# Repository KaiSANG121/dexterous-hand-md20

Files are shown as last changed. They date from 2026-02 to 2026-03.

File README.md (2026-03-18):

# Dexterous Hand Control System for Precision Grasping

A robotics project focused on **precision grasping**, **embedded control**, and **hardware-software integration** using an Arduino-based dexterous hand prototype.

This project presents a dexterous hand control system designed to improve grasp stability for objects of different sizes through a staged control strategy. The system combines a **pinch-first grasping mechanism**, **position-synchronized follower fingers**, and a **fine adjustment mode** for small-object manipulation.

The thumb and index finger are driven by **LV-TTL motors** to perform the primary pinch action, while the remaining three fingers are driven by **PWM servos** to provide follow-up wrapping support. To improve reliability and reduce latency during prototyping, a **button-based control interface** was adopted instead of Bluetooth communication.

---

## Project Highlights

- **Pinch-first grasping strategy** for initial object capture
- **Load-threshold stop logic** for safer and more stable contact
- **Position-synchronized follower fingers** for coordinated wrapping
- **Fine adjustment mode** for small-object grasping
- **Low-latency button-based control** for reliable prototyping
- **Integrated embedded control and robotic hardware implementation**

---

## Motivation

Dexterous robotic grasping requires both precise initial contact and stable follow-up wrapping. In low-cost prototypes, simple open-loop control often leads to unstable grasps, delayed response, or poor performance on small targets.

Dexterous hand precision grasping demo

This project explores a lightweight and practical control solution that balances:

1. **stable initial pinch contact**,
2. **coordinated finger wrapping**,
3. **limited fine adjustment for small or difficult objects**.

The goal was not only to make the hand move, but to design a control strategy that is **interpretable**, **tunable**, and **effective in real hardware tests**.

---

## System Overview

The system is built around an **Arduino controller** and consists of two main actuation groups:

- **Pinch fingers:** thumb and index finger driven by LV-TTL motors for initial object capture
- **Follower fingers:** three PWM-driven fingers for synchronized wrapping after pinch contact

The system uses a **button-based interface** to trigger grasping, opening, and fine adjustment actions. This design was chosen to reduce control latency and improve repeatability during hardware testing.

### Hardware Components

- Arduino Mega2560 (or Mega2560 Pro)
- 2 × LV-TTL motors (pinch fingers)
- 3 × PWM servos (follower fingers)
- push buttons for interaction
- power supply and wiring interface

---

## From Concept to Prototype

<table>
  <tr>
    <td align="center"><b>Concept Design</b></td>
    <td align="center"><b>Physical Prototype</b></td>
  </tr>
  <tr>
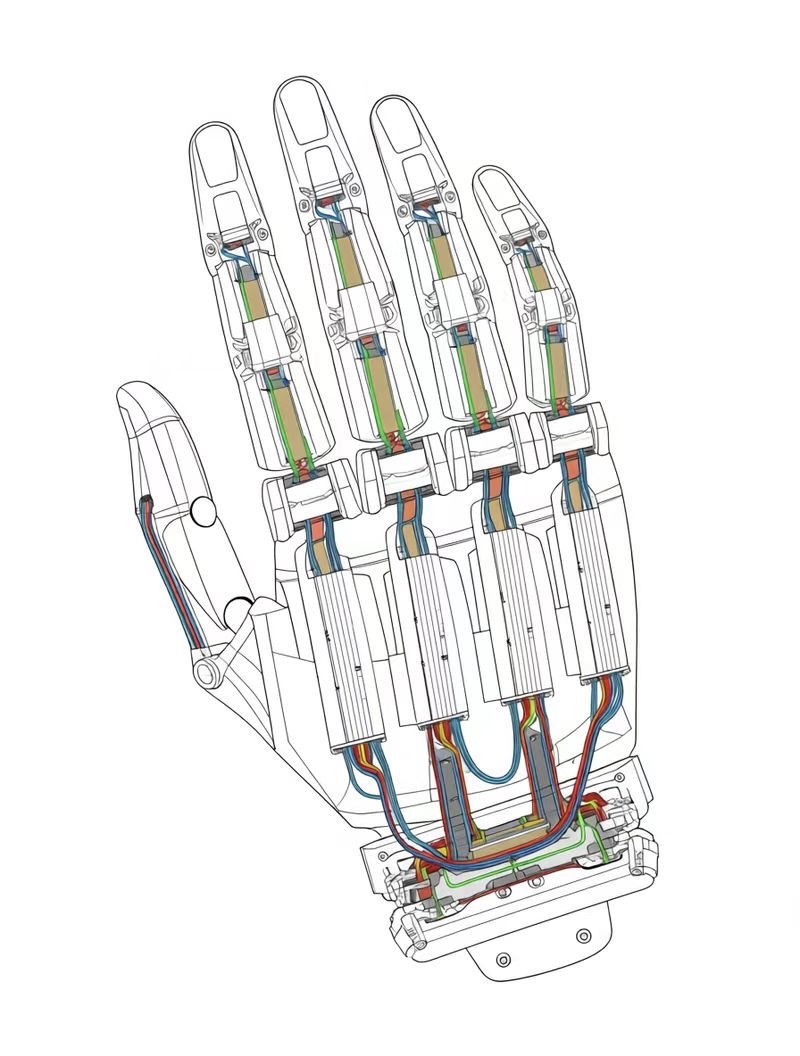
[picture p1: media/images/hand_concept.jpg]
    <td></td>
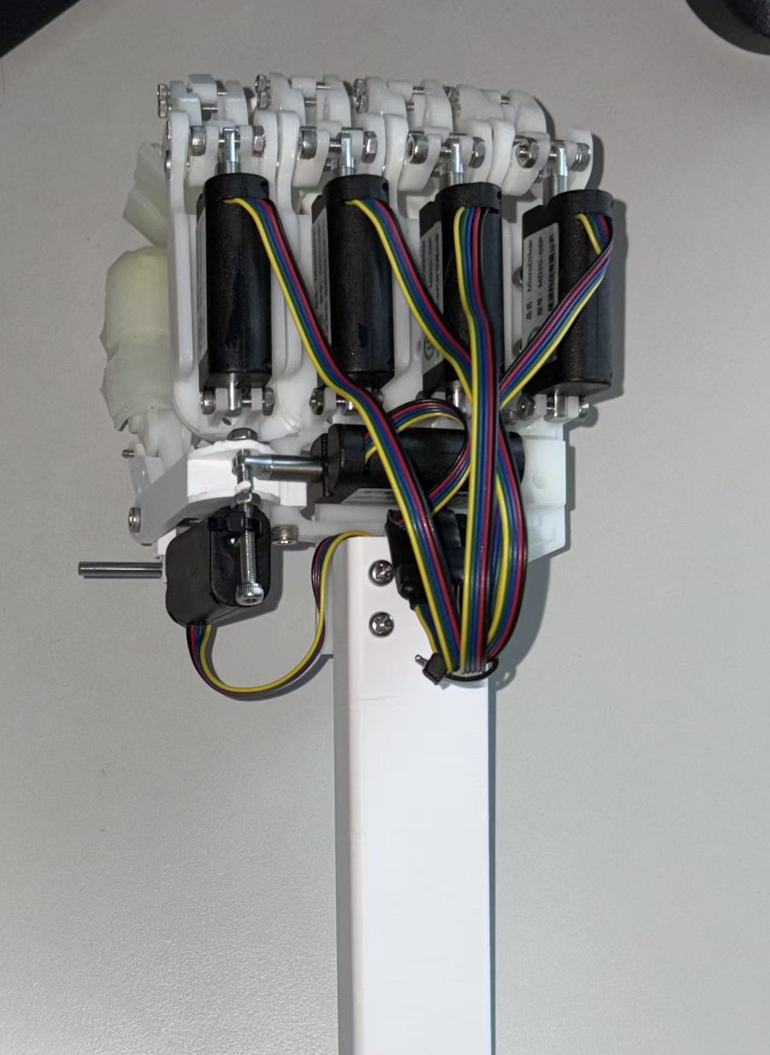
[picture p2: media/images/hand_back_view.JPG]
    <td></td>
  </tr>
</table>

This comparison shows the transition from the early structural concept to the implemented hardware prototype.  
The final system preserves the overall back-side actuator layout and finger arrangement while adapting the design for practical assembly, wiring, and embedded control integration.

---

## Control Strategy

The control logic consists of four main stages.

### 1. Open State
The hand remains open and ready for a new grasp.

### 2. Pinch Phase
The thumb and index finger move toward each other until contact is detected through a **load-threshold condition**.

### 3. Wrap Phase
After pinch contact, the remaining three fingers move according to a **position-synchronized mapping strategy**, improving overall grasp stability.

### 4. Fine Adjustment Phase
For small or difficult objects, an additional **fine adjustment step** is used to slightly refine finger position and improve grasp success.

This staged strategy separates **initial capture** from **grasp stabilization**, making the system easier to tune and analyze during testing.

---

## Design Trade-off: Buttons vs Bluetooth

Although Bluetooth control offers greater flexibility, it introduced additional latency and reduced repeatability during early-stage hardware testing. Since this project focused on **grasp reliability** and **rapid prototyping**, a button-based interface was chosen as a more stable and lower-latency solution.

This reflects an important engineering trade-off:

- sacrificing some communication convenience,
- in order to improve robustness and repeatability during prototype validation.

---

## Wiring and Pin Map

| Module | Connection |
|---|---|
| LV-TTL Motor 1 | Thumb / pinch finger |
| LV-TTL Motor 2 | Index / pinch finger |
| PWM Servo 1 | Follower finger 1 |
| PWM Servo 2 | Follower finger 2 |
| PWM Servo 3 | Follower finger 3 |
| Button A (GRIP) | Grasp trigger |
| Button B (OPEN) | Open / release |
| Button C & D | Fine adjustment for thumb |
| Button E & F | Fine adjustment for index |
| Button G (STOP) | Emergency stop |
| Button H (SYNC) | Synchronized follower fingers |

This table is the hardware role mapping. For exact firmware pin/interface mapping (and to keep README consistent with firmware), see [`docs/wiring.md`](docs/wiring.md).

---

## Key Parameters

The system behavior is mainly affected by the following parameters:

- **motion limits** for pinch fingers
- **load threshold** for contact detection
- **position mapping** between pinch motor and follower fingers
- **fine adjustment step size**
- **initial open position calibration**

A complete calibration and tuning guide is maintained in [`docs/calibration.md`](docs/calibration.md).

---

## Experimental Results

The prototype was tested on objects of different sizes and manipulation tasks. A concise quantitative summary is shown below.

### Quantitative Summary

| Task | Trials | Success | Success Rate |
|---|---:|---:|---:|
| Ping-pong ball grasp | 30 | 30 | 100.0% |
| Rubik's cube grasp | 30 | 30 | 100.0% |
| Water bottle (half full) grasp | 30 | 26 | 86.7% |
| Thumbtack grasp (fine adjust) | 30 | 11 | 36.7% |
| Card pick & insertion | 50 | 46 | 92.0% |
| Bottle cap loosening | 50 | 19 | 38.0% |

### Main Observations

- medium and large objects could be grasped with high stability,
- small objects were more sensitive to alignment and finger position,
- the fine adjustment mode improved grasp feasibility for small targets,
- synchronized follower fingers improved wrapping support after the initial pinch.

For full logs and notes, see [`results/grasp_tests.csv`](results/grasp_tests.csv) and [`results/grasp_summary.md`](results/grasp_summary.md).

---

## Limitations and Future Work

While the current prototype demonstrates stable grasping for medium and large objects, several limitations remain:

- small, thin, or low-friction objects are still difficult to grasp reliably,
- the current system relies on threshold-based contact handling rather than richer tactile sensing,
- follower fingers improve grasp wrapping but do not yet adapt independently to object geometry,
- the overall control strategy is still relatively simple and does not include full closed-loop grasp optimization.

Possible future improvements include:

- grasp success rate comparison across object categories,
- ablation study (pinch only vs pinch + sync vs pinch + sync + fine adjust),
- response time measurement for contact stop and adjustment,
- failure case analysis for small, thin, and low-friction objects,
- adding tactile or force sensing,
- improving closed-loop coordination across all fingers,
- introducing object-specific grasp planning.

---

## Repository Structure

```text
dexterous-hand-md20/
├── docs/           # design notes, calibration, wiring
├── firmware/       # Arduino control code
├── hardware/       # wiring, BOM, hardware-related files
├── media/          # demo videos and images
├── results/        # grasp logs, summaries, test outputs
└── README.md
```

## How to Run

1. Install **Arduino IDE** (recommended 2.x series, e.g. 2.3+).
2. Install required dependency library:
   - `Servo.h` (Arduino Servo library).
3. Open firmware:
   - `firmware/arduino/code/dexterous_hand_controller.ino`.
4. Configure board and serial settings:
   - Board: **Arduino Mega or Mega 2560**,
   - Port: the COM/TTY port connected to your controller,
   - Serial Monitor baud rate: **115200**.
5. Connect motors, servos, and buttons according to [`docs/wiring.md`](docs/wiring.md).
6. Upload firmware, power the system, verify initial open position, and test GRIP/OPEN/SYNC/FINE functions.
7. Tune parameters following [`docs/calibration.md`](docs/calibration.md) if needed.

---

## Media

- Demo GIF: [`media/gifs/demo.gif`](media/gifs/demo.gif)
- Video list and top demonstrations: [`media/videos.md`](media/videos.md)

---

## About the Author

This project reflects my interest in robotic manipulation, embedded control, and hardware-software integration. I focused on control architecture, embedded implementation, hardware-software integration, and iterative grasp testing.

Kaiyang Deng  
Robotics Engineering, South China University of Technology  
GitHub: KaiSANG121

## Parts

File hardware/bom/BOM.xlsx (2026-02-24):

Part Name | Parameter | Cost(¥) | Perchase Link
3D Printed Part | ABS， 0.5mm, Solid | 306.22 | 【淘宝】https://e.tb.cn/h.7Z7FRmGumVoTlou?tk=uKgxfrW5uFN MF287 「3D打印服务模型定制金属abs加工零件手板塑料模具尼龙树脂三D打样」 点击链接直接打开 或者 淘宝搜索直接打开
Nail pick | stainless steel | 13.8 | 【淘宝】7天无理由退货 https://e.tb.cn/h.7ZGgextyRJyaMKB?tk=ogYFfrdvzEo HU926 「不锈钢食指套拇指拨片 银色金色吉他指套民谣指套拨片电吉他指套」 点击链接直接打开 或者 淘宝搜索直接打开
Screws, nuts | stainless steel, M2, M2.5, M3, Hex socket | 81.44 | 【淘宝】假一赔四 https://e.tb.cn/h.70CN3nhS3ggPNhz?tk=rnvZfrWg9KT HU926 「304不锈钢内六角螺丝螺母套装大全螺钉配套组合螺栓M2M3M4M5M6M8」 点击链接直接打开 或者 淘宝搜索直接打开
Gloves | rubber | 7.21
Arduino mega2560 | ATmega2560, 5V, 54 I/O, 16 analog inputs, 16MHz, USB Mini, 38x55mm |  | 【淘宝】https://e.tb.cn/h.7ZGgLPIR855fboq?tk=B7pxfrdEO5d HU591 「STM32F103C8T6最小系统板 STM32单片机开发板套件同款科协江科大」 点击链接直接打开 或者 淘宝搜索直接打开
Sensors |  | 66.95
Vertical tact switch | 6*6*5mm | 2.41
LM2596 multi-channel switch | 3.3V/5V/12V/ADJ, DC

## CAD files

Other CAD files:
hardware/cad/dwg/设计图.DWG
hardware/cad/step/后右.STEP
hardware/cad/step/新底座.STEP
hardware/cad/step/零件10.STEP
hardware/cad/step/F03_Thumb_joint(1).STEP
hardware/cad/step/后左.STEP
hardware/cad/step/前左.STEP
hardware/cad/step/前右.STEP
hardware/cad/step/DIP (1)_3.STEP
hardware/cad/step/零件11.STEP
hardware/cad/step/F03_Thumb_base(1).STEP

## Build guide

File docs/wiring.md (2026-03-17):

# Wiring Guide

This document records the hardware wiring used by the current firmware (`firmware/arduino/code/dexterous_hand_controller.ino`).

## Pin / Interface Mapping

| Module | Connection | Pin / Interface |
|---|---|---|
| LV-TTL Motor 1 | Thumb / pinch finger | `Serial1` (TX1=18, RX1=19) |
| LV-TTL Motor 2 | Index / pinch finger | `Serial2` (TX2=16, RX2=17) |
| PWM Servo 1 | Follower finger 1 | D2 |
| PWM Servo 2 | Follower finger 2 | D6 |
| PWM Servo 3 | Follower finger 3 | D10 |
| Button A (GRIP) | Grasp trigger | D42 |
| Button B (OPEN) | Open / release | D40 |
| Button C | Fine adjustment for thumb (IN) | D25 |
| Button D | Fine adjustment for thumb (OUT) | D27 |
| Button E | Fine adjustment for index (IN) | D29 |
| Button F | Fine adjustment for index (OUT) | D31 |
| Button G (STOP) | Emergency stop | D20 |
| Button H (SYNC) | Synchronized follower fingers | D22 |

## Wiring Notes

- Button inputs use `INPUT_PULLUP` in firmware: released = `HIGH`, pressed = `LOW`.
- Ensure **common ground (GND)** between Arduino, LV-TTL motor power, and servo power.
- Verify power supply current is sufficient for simultaneous servo movement.
- Test with low-speed and emergency STOP available before full-speed operation.

## Firmware Source of Truth

If this document and firmware diverge, firmware definitions are authoritative:

- Button pins: `kBtnOpen`, `kBtnGrip`, `kBtnStop`, `kBtnSync`, `kBtnFineInM1`, `kBtnFineOutM1`, `kBtnFineInM2`, `kBtnFineOutM2`
- PWM pins: `kPwmPins = {2, 6, 10}`
- LV-TTL serial interfaces: comments and motor configuration near the top of the file

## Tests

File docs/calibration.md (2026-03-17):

# Calibration Guide (MD20 LV-TTL + PWM follower fingers)

This document explains how the key parameters in `firmware/arduino/code/dexterous_hand_controller.ino` were calibrated.

## 1. Safety checklist (before calibration)
- Use **low speed** first: `kSpeedOpen/kSpeedClose = 5~10`
- Keep fingers away from hard stops; avoid long time stall
- Ensure **common GND** between Arduino and motor power supply
- Prepare **STOP button (D20)** for emergency hold

---

## 2. LV-TTL motion limits: `kPosMin` / `kPosMax`
**Purpose:** define safe open/close endpoints (avoid hard mechanical stops)

### Procedure
1. With no object in hand, press **OPEN** and observe the thumb+index pair.
2. Slowly move toward open direction and find the **mechanically safe open pose**.
3. Record the corresponding MD20 position as `kPosMin` (current: `80`).
4. Slowly move toward close direction (empty) and find the **safe close pose** (no hard stall).
5. Record the MD20 position as `kPosMax` (current: `320`).

### Tuning tips
- If fingers hit hard stops → **reduce** the limit range (increase `kPosMin` or decrease `kPosMax`)
- If open is not wide enough → **decrease** `kPosMin` carefully (only if still safe)

---

## 3. Load-threshold pinch: `kLoadThreshold`
**Purpose:** stop each LV-TTL finger when contact is detected (load/torque proxy from MD20)

### Observed load range (example)
- **Ping-pong ball grasp:** load ≈ **35 ~ 55**
- We set `kLoadThreshold = 40` so that:
  - empty-close load stays mostly below threshold
  - object contact reliably crosses threshold

### Procedure (recommended)
1. Empty close (no object): press **GRIP**, observe `Load=` prints in Serial Monitor.
2. Grasp typical objects (e.g., ping-pong ball): press **GRIP**, observe contact load.
3. Choose threshold:
   - slightly above empty-close baseline
   - below typical contact load
4. Verify: both sides should stop and hold without continuous stalling.

### Tuning tips
- If it stops too early (weak pinch) → **increase** `kLoadThreshold`
- If it crushes objects / stalls too hard → **decrease** `kLoadThreshold`
- If load readings fluctuate a lot → increase `kMonitorIntervalMs` or reduce speed

---

## 4. PWM follower mapping: `kPwmPulseAtPosMin/Max`
**Purpose:** after pinch, let follower fingers wrap around the object for more friction and stability.

### Finger mapping (this project)
- PWM #1 (D2)  → **Middle finger**
- PWM #2 (D6)  → **Ring finger**
- PWM #3 (D10) → **Pinky**

### Endpoint calibration logic
The firmware does a linear mapping from **Motor2 (index)** position ratio to PWM pulse width:

- At `kPosMin` (open): `kPwmPulseAtPosMin = {1080, 680, 680}`
- At `kPosMax` (close): `kPwmPulseAtPosMax = {1300, 1060, 1120}`

### Procedure
1. Put the index finger (Motor2) at `kPosMin`.  
2. For each PWM finger, adjust pulse until it reaches the desired “open” pose. Record as `kPwmPulseAtPosMin[i]`.
3. Put Motor2 at `kPosMax`.
4. For each PWM finger, adjust pulse until it reaches the desired “wrap/close” pose. Record as `kPwmPulseAtPosMax[i]`.
5. Test **SYNC**: follower fingers should track smoothly as Motor2 moves.

### Tuning tips
- If a PWM finger moves opposite direction → swap min/max pulses for that finger
- If a finger saturates too early → widen pulse range slightly (within safe bounds)
- If servo jitters → ensure stable power supply and common ground

---

## 5. Fine adjustment: `kFineStep` / `kFineFastRegionEnd`
**Purpose:** improve precision for small objects (e.g., thumbtack) without sacrificing speed.

Current values:
- `kFineStep = 40`
- `kFineFastRegionEnd = 280`

### Tuning tips
- For small objects, reduce step size (e.g., `20`) for higher precision
- If fine adjust is too slow, increase step size (e.g., `50~60`)
- Keep the region split to avoid many tiny moves near the endpoint

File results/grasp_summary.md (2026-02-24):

# Grasp & Manipulation Benchmark Summary

This project is evaluated on two levels:
1) **Grasping** (pick & hold objects)
2) **Manipulation** (perform tasks beyond grasping, requiring alignment / insertion / torsion)

---

## 1. Overall Results

### Grasping (object pick & hold)
- **Medium / large rigid objects** (ping-pong ball, Rubik’s cube, half-full water bottle): typically **high success**  
  Key factor: **pinch + full-hand wrap** provides stable normal force and friction.
- **Compliant / deformable objects** (nylon rope, bagged milk, glasses cloth): typically **high success**  
  Key factor: **wrap** reduces slip and stabilizes contact on deformable surfaces.
- **Small objects** (thumbtack): ~**30%** success  
  Primary bottleneck: **pose accuracy** and **contact geometry sensitivity**.

### Manipulation (task completion)
- **Card pick & insertion**: requires **alignment + fine adjustment**  
- **Loosening bottle cap**: requires **torsion + anti-slip stability**, wrap helps maintain grip

> Detailed logs are in `results/grasp_tests.csv`.

---

## 2. Why the design works (mechanism-level explanation)

### (A) Load-threshold pinch (thumb + index, LV-TTL)
During GRIP, each LV-TTL motor closes until `load > kLoadThreshold`, then stops at current pose.
- Prevents excessive squeeze and reduces stall risk
- Provides a consistent “contact detected” event for higher-level behaviors

### (B) Full-hand wrap via SYNC (3× PWM follower fingers)
After pinch contact, pressing SYNC maps **index Motor2 position ratio** to PWM pulses and wraps the object.
- Increases total contact area
- Increases friction and stability
- Especially helpful for deformable objects (rope, fabric, bagged items) and heavier payloads

### (C) Fine adjustment
For small objects, coarse motion is fast but insufficient.
Fine IN/OUT buttons allow incremental pose corrections to improve alignment and contact quality.

---

## 3. Failure Modes (observed)
### Small object grasp (thumbtack)
Common failures:
- slip during initial pinch contact
- misalignment causing ejection
- insufficient normal force at the exact contact geometry

---

## 4. Future Improvements
- Reduce `kFineStep` (e.g., 20) to improve precision for small objects
- Add a “micro-search” routine: approach → detect contact → small local search around pose
- Add sensing on follower fingers (tactile / force / current) to close the loop
- Improve fingertip material (higher friction pads) for small rigid objects

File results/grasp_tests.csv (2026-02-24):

task_type | task_name | object | object_type | material_or_compliance | mode | trials | success | success_rate | notes
grasp | pinch_grasp | pingpong_ball | medium | rigid | pinch | 30 | 30 | 1 | load~35-55; stable pinch & clean release
grasp | fullhand_grasp | rubiks_cube | medium | rigid | fullhand | 30 | 30 | 1 | SYNC wrap improves friction; stable hold
grasp | fullhand_grasp | nylon_rope | flexible | compliant | fullhand | 30 | 30 | 1 | wrap significantly improves stability on deformable object
grasp | fullhand_grasp | bagged_milk | medium | compliant | fullhand | 30 | 29 | 0.966666667 | requires gentle force; load threshold helps avoid over-squeeze
grasp | fullhand_grasp | glasses_cloth | thin_fabric | highly_compliant | fullhand | 30 | 30 | 1 | grasp edges; wrap prevents slip
grasp | fullhand_grasp | water_bottle_half_full | large | rigid+liquid | fullhand | 30 | 26 | 0.866666667 | heavier payload; stable hold with wrap
grasp | fine_object_grasp | thumbtack | small | rigid | fine_adjust | 30 | 11 | 0.366666667 | high pose precision needed; common failure: slip/misalignment
manipulation | peg_insertion | card_pick_and_insert | card | semi_rigid | pinch+fine_adjust | 50 | 46 | 0.92 | pick card from table -> align -> insert; success depends on alignment
manipulation | cap_unscrewing | loosen_bottle_cap | bottle_cap | rigid | pinch+wrap | 50 | 19 | 0.38 | requires torsion + stable normal force; wrap improves anti-slip

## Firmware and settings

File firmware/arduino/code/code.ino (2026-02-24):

#include <Arduino.h>
#include <Servo.h>  

/*
  ==========================================================
  Project: 2x MD20 (LV-TTL) Pinch + 3x PWM Follower Fingers
  Board  : Mega2560 Pro (or Mega2560)
  Author : Kaiyang Deng (repo versioned)

  Features:
  - LV-TTL motors (thumb & index): torque/load-threshold pinch (auto stop on contact)
  - 3x PWM motors: follower fingers track index motor position to increase friction
  - Fine adjustment for both LV-TTL motors (in/out)
  - Button-based control (low latency), plus serial command fallback

  Serial Ports:
    Serial  -> USB monitor (115200)
    Serial1 -> MD20 Motor#1 bus (TX1=18 RX1=19)
    Serial2 -> MD20 Motor#2 bus (TX2=16 RX2=17)
  ==========================================================
*/

// ==========================================================
// ===== 1) Hardware config (pins, ports, calibration) ======
// ==========================================================

// ---------- LV-TTL motors ----------
static const uint8_t  kMotorCount = 2;

// Note: Both IDs are 0x01 because each motor is on a separate UART bus.
// If you put them on the SAME bus, you must use different IDs.
static const uint8_t  kMotorId1 = 0x01;
static const uint8_t  kMotorId2 = 0x01;

static const uint16_t kPosMin = 80;    // open
static const uint16_t kPosMax = 320;   // close
static const uint16_t kSpeedOpen  = 10;
static const uint16_t kSpeedClose = 10;

static const uint16_t kLoadThreshold = 40;     // contact threshold
static const uint32_t kMonitorIntervalMs = 100;

// Fine adjust parameters
static const uint16_t kFineStep = 40;          // coarse fine-adjust step
static const uint16_t kFineFastRegionEnd = 280; // <= this: step by kFineStep; > this: jump to end

// ---------- PWM motors ----------
static const uint8_t kPwmCount = 3;
static const uint8_t kPwmPins[kPwmCount] = {2, 6, 10};
static Servo pwmServos[kPwmCount];

// Calibration: pulse width at LV-TTL pos endpoints (pos=80 and pos=320)
static const int kPwmPulseAtPosMin[kPwmCount] = {1080,  680,  680};
static const int kPwmPulseAtPosMax[kPwmCount] = {1300, 1060, 1120};

// PWM safe bounds
static const int kPwmPulseSafeMin = 500;
static const int kPwmPulseSafeMax = 2500;

// ---------- Buttons (INPUT_PULLUP: released=HIGH, pressed=LOW) ----------
static const int kBtnOpen  = 40;  // OPEN  -> open gripper
static const int kBtnGrip  = 42;  // GRIP  -> auto close until contact
static const int kBtnStop  = 20;  // STOP  -> emergency stop
static const int kBtnSync  = 22;  // SYNC  -> PWM follow motor2 position

static const int kBtnFineInM1  = 25;
static const int kBtnFineOutM1 = 27;
static const int kBtnFineInM2  = 29;
static const int kBtnFineOutM2 = 31;

// ==========================================================
// ========== 2) Data structures / runtime states ===========
// ==========================================================

struct GripperMotor {
  uint8_t id;
  HardwareSerial* port;
  bool closing;     // is currently commanded to close
  bool contact;     // has reached contact threshold
  uint16_t pos;     // cached position
  uint16_t load;    // cached load
};

static GripperMotor motors[kMotorCount] = {
  {kMotorId1, &Serial1, false, false, 0, 0},  // Motor 1
  {kMotorId2, &Serial2, false, false, 0, 0}   // Motor 2 (index finger in your design)
};

static bool     gGlobalClosing = false;
static uint32_t gLastMonitorMs = 0;

// Button edge detection
static bool lastOpenState      = HIGH;
static bool lastGripState      = HIGH;
static bool lastStopState      = HIGH;
static bool lastSyncState      = HIGH;
static bool lastFineInM1State  = HIGH;
static bool lastFineOutM1State = HIGH;
static bool lastFineInM2State  = HIGH;
static bool lastFineOutM2State = HIGH;

// ==========================================================
// ========== 3) Gripper protocol (MD20 LV-TTL) ==============
// ==========================================================

static uint8_t md20Checksum(uint8_t id, uint8_t len, uint8_t func,
                            const uint8_t* params, uint8_t paramLen) {
  uint16_t sum = id + len + func;
  for (uint8_t i = 0; i < paramLen; i++) sum += params[i];
  return (uint8_t)(~(sum & 0xFF));
}

static void md20SendPacket(HardwareSerial& port,
                           uint8_t id, uint8_t func,
                           const uint8_t* params, uint8_t paramLen) {
  const uint8_t len = paramLen + 2;
  const uint8_t checksum = md20Checksum(id, len, func, params, paramLen);

  port.write(0xFF);
  port.write(0xFF);
  port.write(id);
  port.write(len);
  port.write(func);
  for (uint8_t i = 0; i < paramLen; i++) port.write(params[i]);
  port.write(checksum);
}

static bool md20ReadPosSpdLoad(HardwareSerial& port, uint8_t id,
                               uint16_t& pos,
                               uint16_t& spd,
                               uint16_t& load,
                               uint8_t&  statusOut) {
  // Flush old bytes
  while (port.available() > 0) (void)port.read();

  // Read 8 bytes from start address 0x38
  uint8_t params[2];
  params[0] = 0x38;
  params[1] = 0x08;
  md20SendPacket(port, id, 0x02, params, 2);

  const uint8_t expectedBytes = 14; // header(2) + id + len + status + data(8) + checksum
  const uint32_t timeoutMs = 100;

  const uint32_t t0 = millis();
  while (port.available() < expectedBytes && (millis() - t0) < timeoutMs) {}

  if (port.available() < expectedBytes) return false;

  const uint8_t h1 = port.read();
  const uint8_t h2 = port.read();
  if (h1 != 0xDD || h2 != 0xDD) return false;

  const uint8_t recvId = port.read();
  (void)port.read();          // len (unused)
  const uint8_t status = port.read();
  if (recvId != id) return false;

  uint8_t data[8];
  for (uint8_t i = 0; i < 8; i++) data[i] = port.read();
  (void)port.read();          // checksum (not verified)

  statusOut = status;
  pos  = ((uint16_t)data[0] << 8) | data[1];
  spd  = ((uint16_t)data[2] << 8) | data[3];
  load = ((uint16_t)data[4] << 8) | data[5];
  return true;
}

static void md20WritePosSpeed(HardwareSerial& port, uint8_t id,
                              uint16_t pos, uint16_t speed) {
  uint8_t params[5];
  params[0] = 0x2A;
  params[1] = (pos >> 8) & 0xFF;
  params[2] = pos & 0xFF;
  params[3] = (speed >> 8) & 0xFF;
  params[4] = speed & 0xFF;
  md20SendPacket(port, id, 0x03, params, sizeof(params));
}

static void md20StopAtCurrent(GripperMotor& m) {
  uint16_t pos, spd, load;
  uint8_t status;
  if (!md20ReadPosSpdLoad(*m.port, m.id, pos, spd, load, status)) {
    pos = m.pos; // fallback to cached pos
  }
  md20WritePosSpeed(*m.port, m.id, pos, 0);
}

// ==========================================================
// ===== 4) High-level behaviors (Open/Grip/Stop/Sync) ======
// ==========================================================

static void openGripper() {
  Serial.println(F("[GRIPPER] Open -> POS_MIN"));
  for (uint8_t i = 0; i < kMotorCount; i++) {
    motors[i].closing = false;
    motors[i].contact = false;
    md20WritePosSpeed(*motors[i].port, motors[i].id, kPosMin, kSpeedOpen);
  }
  gGlobalClosing = false;
}

static void startCloseGripper() {
  Serial.println(F("[GRIPPER] Close -> POS_MAX (stop on load threshold)"));
  for (uint8_t i = 0; i < kMotorCount; i++) {
    motors[i].closing = true;
    motors[i].contact = false;
    md20WritePosSpeed(*motors[i].port, motors[i].id, kPosMax, kSpeedClose);
  }
  gGlobalClosing = true;
}

static void emergencyStopAll() {
  Serial.println(F("[GRIPPER] EMERGENCY STOP!"));
  for (uint8_t i = 0; i < kMotorCount; i++) {
    md20StopAtCurrent(motors[i]);
    motors[i].closing = false;
    motors[i].contact = true; // treat as "done" to stop logic
  }
  gGlobalClosing = false;
}

// PWM follower: map Motor2 position ratio -> 3 PWM pulses
static int clampInt(int v, int lo, int hi) {
  if (v < lo) return lo;
  if (v > hi) return hi;
  return v;
}

static uint16_t clampU16(uint16_t v, uint16_t lo, uint16_t hi) {
  if (v < lo) return lo;
  if (v > hi) return hi;
  return v;
}

static void pwmFollowMotor2() {
  // IMPORTANT: "Motor2" is motors[1]
  uint16_t pos2 = motors[1].pos;
  pos2 = clampU16(pos2, kPosMin, kPosMax);

  Serial.print(F("[PWM] Follow Motor2 pos="));
  Serial.println(pos2);

  const long denom = (long)(kPosMax - kPosMin);
  if (denom == 0) return;

  for (uint8_t i = 0; i < kPwmCount; i++) {
    const long num = (long)(pos2 - kPosMin) * (kPwmPulseAtPosMax[i] - kPwmPulseAtPosMin[i]);
    int target = kPwmPulseAtPosMin[i] + (int)(num / denom);
    target = clampInt(target, kPwmPulseSafeMin, kPwmPulseSafeMax);

    pwmServos[i].writeMicroseconds(target);

    Serial.print(F("[PWM] Motor"));
    Serial.print(i + 1);
    Serial.print(F(" pulse="));
    Serial.println(target);
  }
}

// ==========================================================
// ========== 5) Fine adjustment (generic helper) ============
// ==========================================================

static void fineAdjust(uint8_t motorIndex, bool inward) {
  if (motorIndex >= kMotorCount) return;

  GripperMotor& m = motors[motorIndex];
  uint16_t pos = clampU16(m.pos, kPosMin, kPosMax);

  Serial.print(F("[FINE] M"));
  Serial.print(motorIndex + 1);
  Serial.print(inward ? F(" IN  ") : F(" OUT "));
  Serial.print(F("pos="));
  Serial.println(pos);

  if (inward) {
    if (pos >= kPosMax) {
      Serial.println(F("[FINE] Already at POS_MAX."));
      return;
    }
    uint16_t target = (pos <= kFineFastRegionEnd) ? (pos + kFineStep) : kPosMax;
    if (target > kPosMax) target = kPosMax;

    Serial.print(F("[FINE] target="));
    Serial.println(target);

    m.closing = false;
    md20WritePosSpeed(*m.port, m.id, target, kSpeedClose);
  } else {
    if (pos <= kPosMin) {
      Serial.println(F("[FINE] Already at POS_MIN."));
      return;
    }
    uint16_t target = (pos > (kPosMin + kFineStep)) ? (pos - kFineStep) : kPosMin;
    if (target < kPosMin) target = kPosMin;

    Serial.print(F("[FINE] target="));
    Serial.println(target);

    m.closing = false;
    md20WritePosSpeed(*m.port, m.id, target, kSpeedOpen);
  }
}

// Convenience wrappers (keep your original semantics)
static void fineAdjustInMotor1()  { fineAdjust(0, true);  }
static void fineAdjustOutMotor1() { fineAdjust(0, false); }
static void fineAdjustInMotor2()  { fineAdjust(1, true);  }
static void fineAdjustOutMotor2() { fineAdjust(1, false); }

// ==========================================================
// ================ 6) Button handler (edge) =================
// ==========================================================

static void handleButtons() {
  const bool openState      = digitalRead(kBtnOpen);
  const bool gripState      = digitalRead(kBtnGrip);
  const bool stopState      = digitalRead(kBtnStop);
  const bool syncState      = digitalRead(kBtnSync);
  const bool fineInM1State  = digitalRead(kBtnFineInM1);
  const bool fineOutM1State = digitalRead(kBtnFineOutM1);
  const bool fineInM2State  = digitalRead(kBtnFineInM2);
  const bool fineOutM2State = digitalRead(kBtnFineOutM2);

  // Detect HIGH -> LOW edge (pressed)
  if (lastOpenState == HIGH && openState == LOW) {
    Serial.println(F("[BTN] OPEN"));
    openGripper();
  }
  if (lastGripState == HIGH && gripState == LOW) {
    Serial.println(F("[BTN] GRIP"));
    startCloseGripper();
  }
  if (lastStopState == HIGH && stopState == LOW) {
    Serial.println(F("[BTN] STOP"));
    emergencyStopAll();
  }
  if (lastSyncState == HIGH && syncState == LOW) {
    Serial.println(F("[BTN] SYNC (PWM follow)"));
    pwmFollowMotor2();
  }
  if (lastFineInM1State == HIGH && fineInM1State == LOW) {
    Serial.println(F("[BTN] FINE IN M1"));
    fineAdjustInMotor1();
  }
  if (lastFineOutM1State == HIGH && fineOutM1State == LOW) {
    Serial.println(F("[BTN] FINE OUT M1"));
    fineAdjustOutMotor1();
  }
  if (lastFineInM2State == HIGH && fineInM2State == LOW) {
    Serial.println(F("[BTN] FINE IN M2"));
    fineAdjustInMotor2();
  }
  if (lastFineOutM2State == HIGH && fineOutM2State == LOW) {
    Serial.println(F("[BTN] FINE OUT M2"));
    fineAdjustOutMotor2();
  }

  lastOpenState      = openState;
  lastGripState      = gripState;
  lastStopState      = stopState;
  lastSyncState      = syncState;
  lastFineInM1State  = fineInM1State;
  lastFineOutM1State = fineOutM1State;
  lastFineInM2State  = fineInM2State;
  lastFineOutM2State = fineOutM2State;
}

// ==========================================================
// ================== 7) Arduino entry points ===============
// ==========================================================

static void printPinMap() {
  Serial.println(F("=== Pin Map (buttons, INPUT_PULLUP) ==="));
  Serial.print(F(" OPEN  : D")); Serial.println(kBtnOpen);
  Serial.print(F(" GRIP  : D")); Serial.println(kBtnGrip);
  Serial.print(F(" STOP  : D")); Serial.println(kBtnStop);
  Serial.print(F(" SYNC  : D")); Serial.println(kBtnSync);
  Serial.print(F(" FINE IN  M1 : D")); Serial.println(kBtnFineInM1);
  Serial.print(F(" FINE OUT M1 : D")); Serial.println(kBtnFineOutM1);
  Serial.print(F(" FINE IN  M2 : D")); Serial.println(kBtnFineInM2);
  Serial.print(F(" FINE OUT M2 : D")); Serial.println(kBtnFineOutM2);
  Serial.println();
}

void setup() {
  Serial.begin(115200);
  Serial1.begin(115200);
  Serial2.begin(115200);

  // Attach PWM servos, init to "pos=min" pulse
  for (uint8_t i = 0; i < kPwmCount; i++) {
    pwmServos[i].attach(kPwmPins[i]);
    pwmServos[i].writeMicroseconds(kPwmPulseAtPosMin[i]);
  }

  // Buttons
  pinMode(kBtnOpen,        INPUT_PULLUP);
  pinMode(kBtnGrip,        INPUT_PULLUP);
  pinMode(kBtnStop,        INPUT_PULLUP);
  pinMode(kBtnSync,        INPUT_PULLUP);
  pinMode(kBtnFineInM1,    INPUT_PULLUP);
  pinMode(kBtnFineOutM1,   INPUT_PULLUP);
  pinMode(kBtnFineInM2,    INPUT_PULLUP);
  pinMode(kBtnFineOutM2,   INPUT_PULLUP);

  Serial.println(F("=== Dual MD20 (LV-TTL) + 3xPWM + Buttons + Fine Adjust Ready ==="));
  printPinMap();

  openGripper();
}

void loop() {
  // 1) Physical buttons
  handleButtons();

  // 2) Serial command fallback
  if (Serial.available() > 0) {
    const char c = (char)Serial.read();
    if      (c == '1') openGripper();
    else if (c == '2') startCloseGripper();
    else if (c == '3') emergencyStopAll();
    else if (c == '4') pwmFollowMotor2();
  }

  // 3) LV-TTL monitoring & auto-stop logic
  const uint32_t now = millis();
  if (now - gLastMonitorMs >= kMonitorIntervalMs) {
    gLastMonitorMs = now;

    bool allContact = true;

    for (uint8_t i = 0; i < kMotorCount; i++) {
      uint16_t pos, spd, load;
      uint8_t status;
      const bool ok = md20ReadPosSpdLoad(*motors[i].port, motors[i].id, pos, spd, load, status);

      if (ok) {
        motors[i].pos  = pos;
        motors[i].load = load;

        Serial.print(F("[M"));
        Serial.print(i + 1);
        Serial.print(F("] Pos="));
        Serial.print(pos);
        Serial.print(F(" Load="));
        Serial.print(load);
        Serial.print(F(" Status="));
        Serial.println(status);

        if (gGlobalClosing && motors[i].closing && !motors[i].contact) {
          if (load > kLoadThreshold) {
            Serial.print(F("  -> M"));
            Serial.print(i + 1);
            Serial.println(F(" reached load threshold, stop."));
            motors[i].contact = true;
            motors[i].closing = false;
            md20StopAtCurrent(motors[i]);
          }
        }
      } else {
        Serial.print(F("[M"));
        Serial.print(i + 1);
        Serial.println(F("] read failed."));
      }

      if (!motors[i].contact) allContact = false;
    }

    if (gGlobalClosing && allContact) {
      Serial.println(F("[GRIPPER] Grip complete (both sides contact)."));
      gGlobalClosing = false;
    }
  }
}

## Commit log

2026-02-24 chore: enable git lfs for CAD and large assets
2026-02-24 feat: initial project structure, firmware, and demo
    [BOM.xlsx, DIP (1)_3.STEP, F03_Thumb_base(1).STEP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]
2026-02-24 docs: improve README with wiring, quickstart, and parameter guide
2026-02-24 docs: refine grasp/manipulation benchmarks
    [grasp_tests.csv]
2026-02-24 docs: add calibration guide and consolidate video links
2026-03-17 Rename Arduino sketch and reorganize code sections
2026-03-17 Improve README reproducibility and add wiring documentation
2026-03-17 Align README wiring table with provided hardware mapping
2026-03-18 Add concept-to-prototype comparison section in README
